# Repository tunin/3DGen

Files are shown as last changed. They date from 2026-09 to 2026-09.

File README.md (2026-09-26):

# Robôzinho — projeto para impressão 3D

Robô paramétrico em [OpenSCAD](https://openscad.org) com ~17 cm de altura:

- **Base** com 4 rodas (2 eixos + travas) e baia para **4 pilhas AA**
- **Torso** com bolso para placa **micro:bit** (a placa desliza por trilhos
  internos a partir de uma fenda no topo) e **2 furos para botões** de 12 mm
- **Cabeça** com janela 34×34 para **matriz de LED 8×8** (~32 mm) ou display
  OLED pequeno — o módulo desliza por trilhos a partir de uma fenda no topo;
  antena e "orelhas" decorativas
- **2 braços articulados** (ombro + cotovelo) com garra de 2 dedos

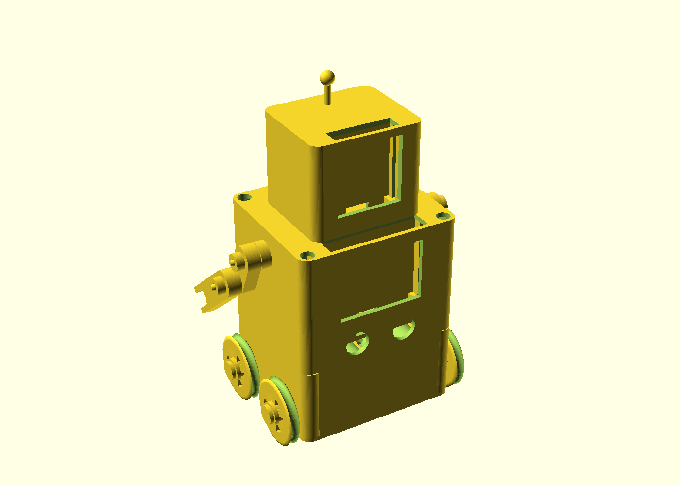
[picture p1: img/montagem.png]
Montagem


**[Manual ilustrado de montagem (PDF)](manual/manual_montagem.pdf)** —
8 etapas em português, com vistas de encaixe e observações essenciais.

Para regenerar o PDF com as peças atuais, instale as dependências de
`manual/requirements.txt` e execute `python manual/gerar_manual.py`.
Requer OpenSCAD; `OPENSCAD` permite indicar o executável. O gerador reutiliza
as imagens intermediárias em `manual/.cache/`; use `--force` para refazê-las.

## Peças para imprimir

| Arquivo STL | Qtd | Observações |
|---|---|---|
| `stl/base.stl` | 1 | Chassi — abertura para cima |
| `stl/corpo.stl` | 1 | Torso — abertura para baixo |
| `stl/cabeca.stl` | 1 | Cabeça — de pé |
| `stl/roda.stl` | 4 | Sulco no aro para elástico como "pneu" |
| `stl/eixo.stl` | 2 | Eixo em pé e trava separados; usar brim (ou eixo metálico M4 de comprimento adequado) |
| `stl/suporte_pilhas.stl` | 1 | Berço 4×AA (ou use suporte comercial) |
| `stl/braco.stl` | 2 | Cada arquivo traz os 2 segmentos do braço |
| `stl/pino.stl` | 4 | Pino + trava das articulações (ou M4×20 + porca) |

## Fatiamento sugerido

- Material: PLA (ou PETG)
- Altura de camada: 0,2 mm — perímetros: 3 — preenchimento: 15–20%
- Torso e cabeça: confira suportes para prateleiras, ressaltos e teto; os painéis internos agora começam na base, mas isso não elimina pontes e balanços. Verifique no fatiador o acesso para remover os suportes antes de imprimir.
- Eixo: imprimir em pé, apoiado na cabeça, com brim. A haste é longa e fina; para maior resistência, prefira eixo metálico. A trava deve aparecer como outra peça, não fundida à haste.
- Rodas: assente o cubo na mesa e confira o suporte sob aro e raios no fatiador.
- Tolerâncias: `folga = 0.3`, `folga_berco = 0.6` e `aperto_trava = 0.1` em `parametros.scad`. O último valor é interferência diametral, não folga radial. Faça um teste de pino/trava antes do lote.
- Imprima os arquivos de peças separadamente. `stl/montagem.stl` é referência visual, não um kit pronto para imprimir: contém contatos e encaixes por pressão intencionais.

## Hardware necessário

- 1 placa **micro:bit** (51,6 × 42 mm)
- 1 **matriz de LED 8×8** MAX7219 (~32 × 32 mm) ou OLED similar — para o rosto
- 2 **botões de painel** de 12 mm
- 1 **suporte de pilhas 4×AA** com interruptor (~62 × 58 × 17 mm)
  — ou use o berço impresso (requer contatos/molas próprios)
- 4 parafusos **M3 × 20** autoroscantes (torso ↔ chassi)
- Articulações dos braços: 4 pinos impressos **ou** parafusos **M4 × 20**
  com porcas autotravantes
- Elásticos/aneis de borracha para os "pneus" das rodas (opcional)

## Montagem

Use base, torso e berço desta mesma revisão: os centros das colunas passaram
para X = ±36,5 mm (Y = ±32 mm). Não misture essas peças com as versões antigas.

1. Monte os botões, os pinos dos ombros e a fiação no torso enquanto o fundo
   está acessível. Os botões ficam abaixo do micro:bit; confira as medidas
   do corpo, da porca e dos terminais do seu modelo.
2. Deslize o micro:bit pela fenda superior até as prateleiras. Passe os fios
   pela abertura do painel interno antes de fechar o conjunto.
3. Apoie o berço impresso ou suporte comercial nas duas travessas elevadas
   do chassi. O plano de apoio fica a 18,6 mm do fundo; a base tem 40 mm de
   altura. O berço tem 0,6 mm de folga nominal nas colunas. Um envelope
   comercial de 62 × 58 × 17 mm, inclusive com cantos retos, cabe centralizado.
4. Conecte a fiação necessária, assente o torso na base e introduza os quatro
   M3 × 20 pelos acessos de 7 mm no topo. Use cabeça de parafuso de até 6 mm
   e chave com haste de até 6 mm, com alcance útil mínimo de 56 mm. Aperte
   nas colunas sem forçar o plástico; não tente parafusar pelo fundo da base.
5. Instale o display e sua fiação na cabeça. Há uma saída sob o display para
   os fios alcançarem o interior e uma passagem central de 12 × 8 mm,
   alinhada à passagem do torso. Confira os conectores antes de fechar.
6. Monte os antebraços pelo lado externo dos cotovelos, com 0,3 mm entre os
   segmentos. Use os pinos atualizados e suas travas ou parafusos M4.
   A montagem de referência agora mostra também os pinos e travas.
7. Encaixe a cabeça nos quatro pinos. Eles têm 4,4 mm de altura e folga axial;
   o encaixe é removível, sem trava de retenção. Não use os fios para segurá-la.
8. Encaixe a primeira roda no eixo antes de atravessar o chassi, depois
   coloque a segunda roda e a trava externa. Repita no outro eixo e confira
   se as rodas giram sem raspar.

### Dimensões da eletrônica

Os testes usam envelopes conservadores, não modelos de componentes específicos:

| Componente | Envelope configurado | Entrada / acomodação |
|---|---|---|
| micro:bit | 51,6 × 42 × 11 mm | Fenda de 52,2 × 11,6 mm; apoio a 18 mm do fundo do torso |
| Display | Até 33 × 33 × 8 mm | Fenda de 33,6 × 8,6 mm; apoio a 8 mm do fundo da cabeça |
| Suporte comercial | 62 × 58 × 17 mm | Centralizado, com cantos retos e sem acessórios fora desse envelope |
| Botões | Corpo de 12 mm, profundidade interna até 10 mm | Porca com envelope de até 16 mm de diâmetro e 3 mm de espessura |

Meça a placa completa, USB/JST, soldas, cabos, interruptor e terminais. Ajuste
`mb_prof`, `led_prof`, `botao_prof` e os demais parâmetros se necessário e
rode os testes novamente. A passagem central não garante a passagem de
qualquer conector: o túnel sob o display tem 12 × 5 mm; um caminho de 3 × 3 mm
para fios foi verificado. O berço impresso continua exigindo contatos elétricos
próprios. A validação mecânica não valida o circuito de alimentação.

## Regenerar os STLs

Requer `openscad` (e `xvfb` para as imagens no Linux). Linux:

```bash
make            # gera stl/*.stl
make img        # gera img/*.png (xvfb-run)
```

Windows (Git Bash, sem `make`/`xvfb`):

```bash
./render_stl.sh   # gera stl/*.stl
./render_img.sh   # gera img/*.png
```

Se `openscad` não estiver no `PATH`, os scripts usam
`C:\Program Files\OpenSCAD\openscad.com` ou a variável `OPENSCAD`.
Os PNGs usam renderização completa (`--render`), evitando artefatos do
preview rápido. Na interface do OpenSCAD, use F6 para conferir a geometria
final; F5 é apenas uma prévia.

Ou diretamente:

```bash
openscad -o stl/roda.stl -D 'part="roda"' robo.scad
```

Peças disponíveis em `part`: `montagem`, `base`, `suporte_pilhas`, `roda`,
`eixo`, `corpo`, `cabeca`, `braco`, `pino`.

## Validação geométrica

Requer Python 3 e OpenSCAD; não usa pacotes Python adicionais:

```bash
python -B -m unittest -v test_geometry
```

Os testes renderizam malhas temporárias e verificam rodas, eixos, pilhas,
berço, articulações e fixadores. Também verificam o layout de impressão do
eixo, acesso dos parafusos e da ferramenta, inserção da eletrônica e do
suporte comercial, espaço dos botões, passagem dos fios e assentamento da
cabeça e do torso. As seções dos painéis internos são verificadas contra o
início de impressão no ar encontrado na auditoria; isso não substitui a
inspeção de todas as camadas no fatiador. Os layouts do braço e do eixo devem
conter exatamente dois sólidos fechados. `OPENSCAD` pode indicar o executável.

As rodas de 36 mm têm 42 mm entre centros (6 mm livres entre elas).
A validação digital não garante as tolerâncias reais da impressora nem o
encaixe de contatos elétricos, molas e suportes comerciais: teste os
encaixes antes de imprimir o conjunto completo.

## Personalizar

Todas as cotas estão em [`parametros.scad`](parametros.scad) — diâmetro das
rodas, dimensões do chassi/torso/cabeça, posição dos botões, tamanho da
janela do display etc. Edite e regenere os STLs.

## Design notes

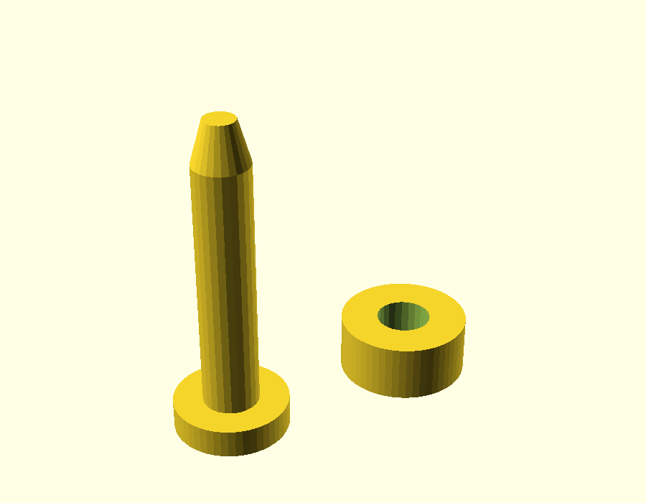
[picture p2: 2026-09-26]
img/pino.png

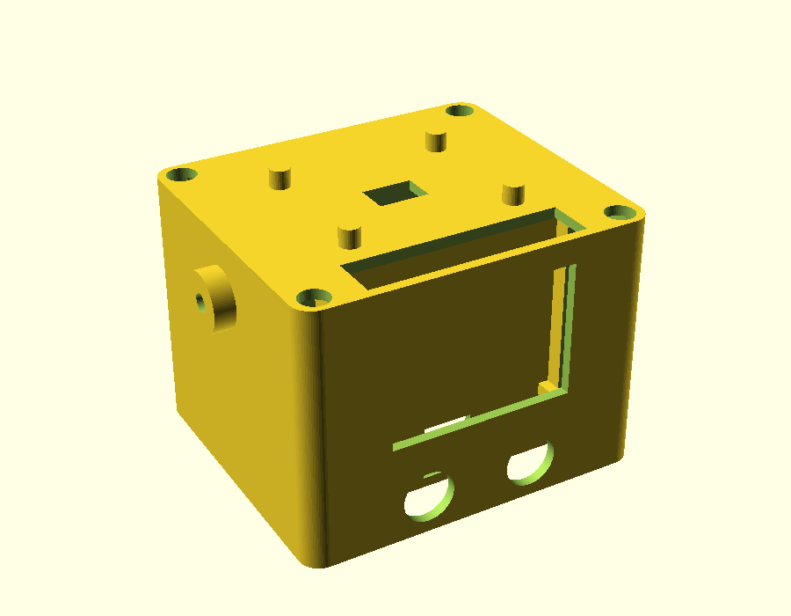
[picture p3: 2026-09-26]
img/corpo.png

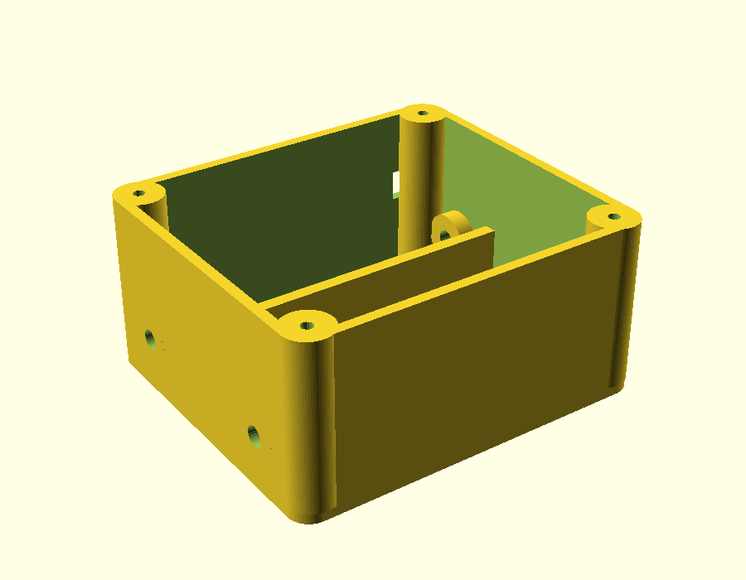
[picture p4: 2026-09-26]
img/base.png

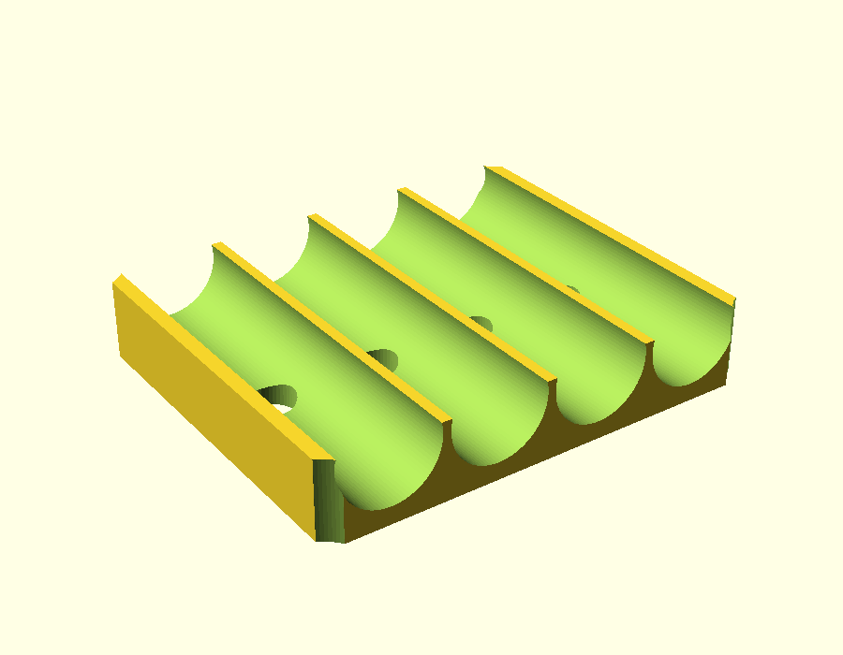
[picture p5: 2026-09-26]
img/suporte_pilhas.png

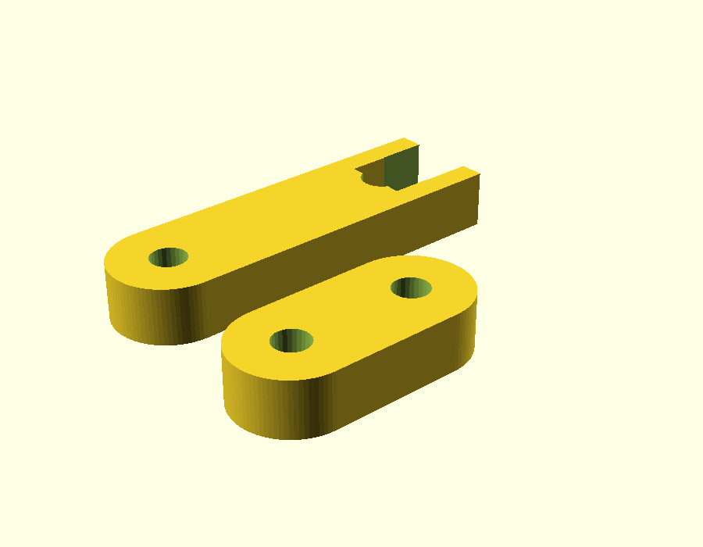
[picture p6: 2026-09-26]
img/braco.png

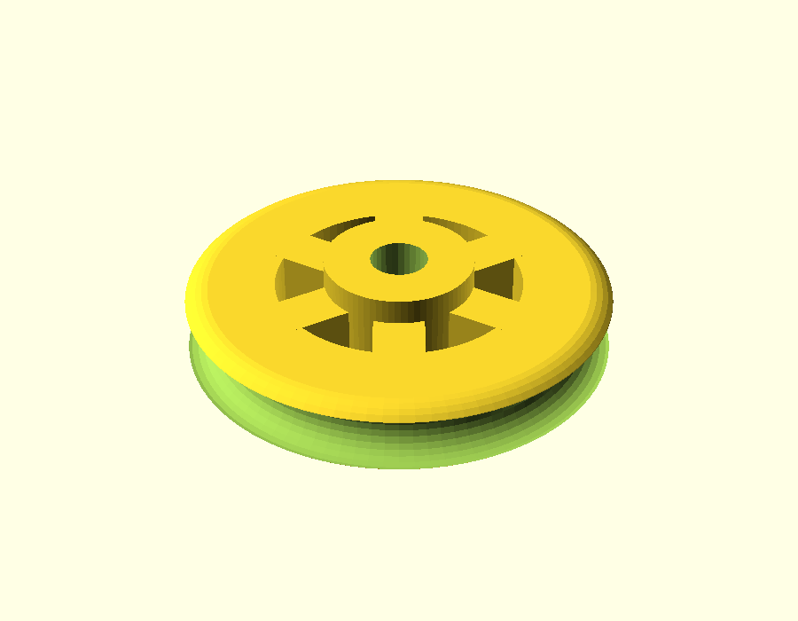
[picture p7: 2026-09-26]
img/roda.png

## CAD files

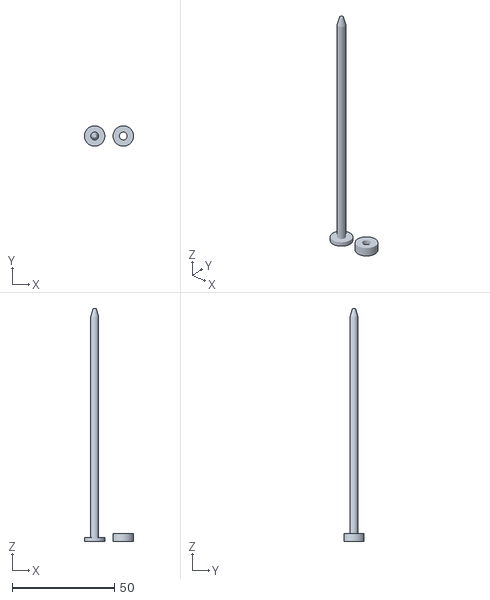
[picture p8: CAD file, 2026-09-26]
stl/eixo.stl
24.0 x 10.00 x 114.0

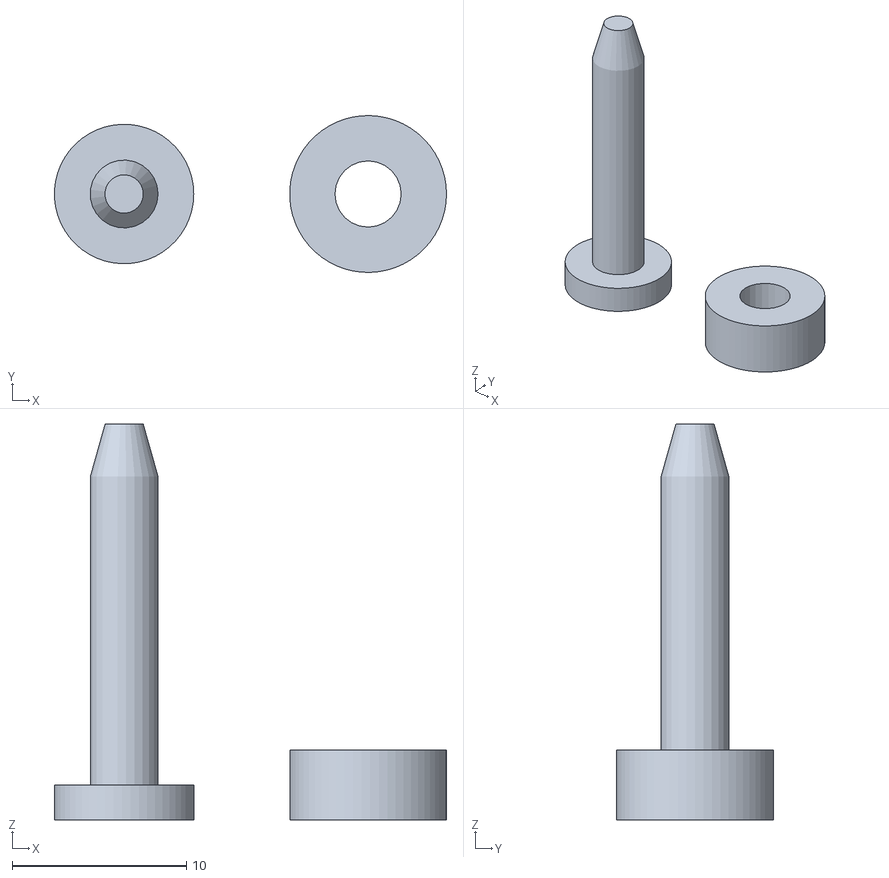
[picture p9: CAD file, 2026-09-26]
stl/pino.stl
22.5 x 9.00 x 22.7

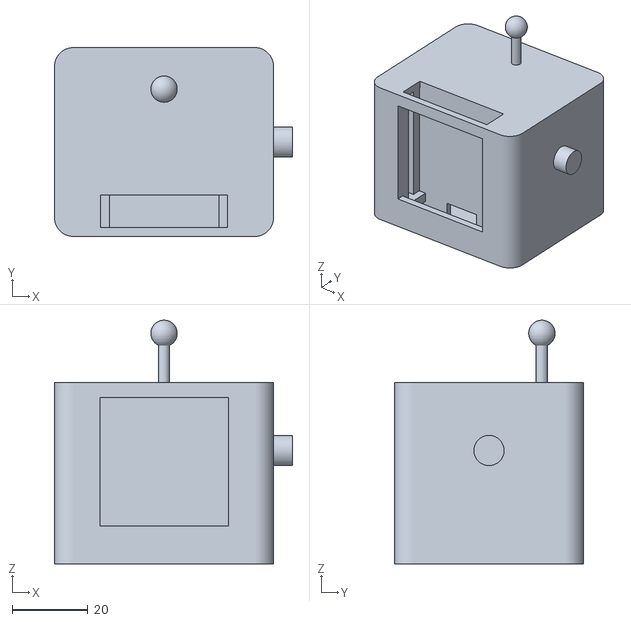
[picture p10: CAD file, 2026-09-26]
stl/cabeca.stl
63.0 x 50.0 x 64.5

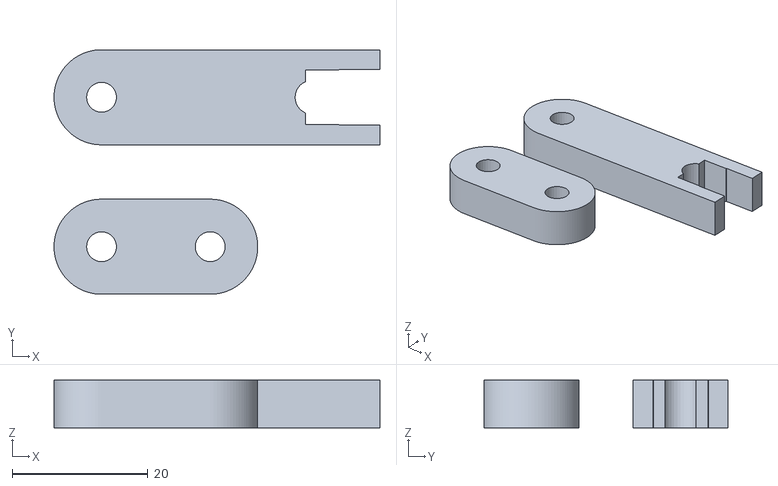
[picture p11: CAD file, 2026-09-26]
stl/braco.stl
48.0 x 36.0 x 7.00

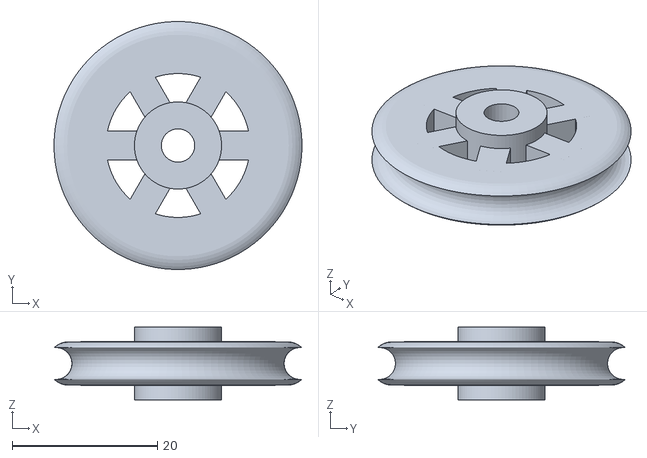
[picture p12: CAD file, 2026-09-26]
stl/roda.stl
34.1 x 34.1 x 10.0

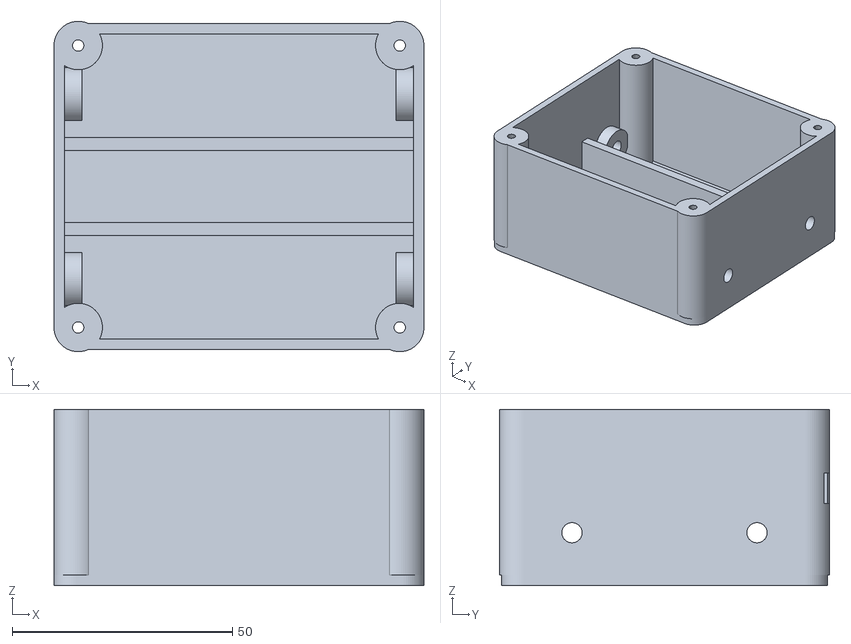
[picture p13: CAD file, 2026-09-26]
stl/base.stl
84.0 x 75.0 x 40.0

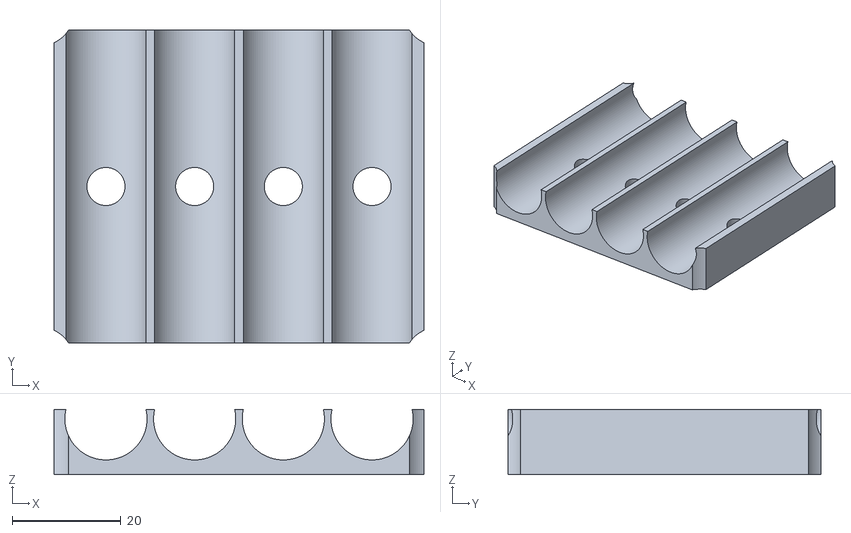
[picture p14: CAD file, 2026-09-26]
stl/suporte_pilhas.stl
68.0 x 57.5 x 12.0

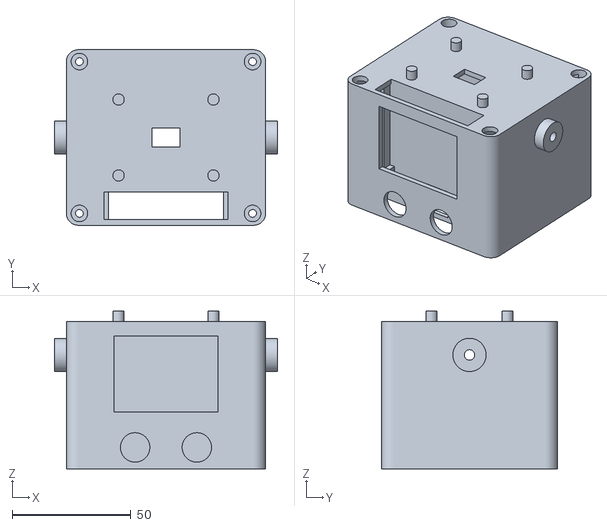
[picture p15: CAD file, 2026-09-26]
stl/corpo.stl
94.0 x 74.0 x 66.4

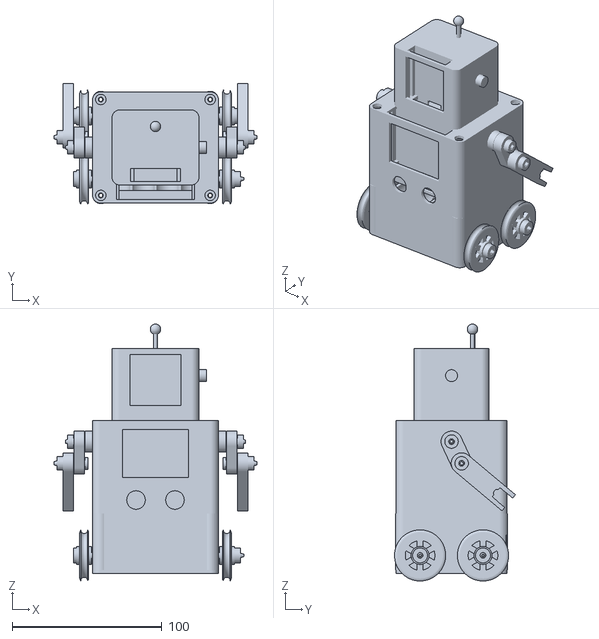
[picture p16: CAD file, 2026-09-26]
stl/montagem.stl
135.4 x 80.7 x 171.6

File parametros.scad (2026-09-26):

// ============================================================
// parametros.scad — dimensões compartilhadas do robô
// Todas as medidas em milímetros.
// ============================================================

$fa = 4;
$fs = 0.5;

// ---------- tolerância de impressão ----------
folga = 0.3;        // folga padrão em furos/encaixes
folga_berco = 0.6;
aperto_trava = 0.1;
passagem_w = 12;
passagem_d = 8;

// ---------- roda ----------
roda_d   = 36;      // diâmetro da roda
roda_w   = 10;      // largura da roda
eixo_d   = 4;       // diâmetro do eixo (haste impressa ou M4)
eixo_l   = 112;     // comprimento do eixo (haste + chanfro)

// ---------- base (chassi) ----------
base_w  = 84;       // largura (X)
base_d  = 74;       // profundidade (Y)
base_h  = 40;       // altura
parede  = 2.4;      // espessura das paredes (todas as peças)
eixo_z  = 12;       // altura do centro do eixo medida do fundo do chassi
roda_y  = roda_d/2 + 3;       // distância do centro do chassi ao centro de cada roda (Y)

// ---------- compartimento das pilhas ----------
// baia dimensionada para suporte comercial 4xAA (~62 x 58 x 17)
// ou para o suporte impresso em suporte_pilhas.scad
aa_bay_w = 72;
aa_bay_d = 58;
aa_dia   = 14.5;    // diâmetro da pilha AA
aa_comp  = 50.5;    // comprimento da pilha AA
suporte_z = eixo_z + 6 + 2*folga;
roda_x = base_w/2 + 2*folga + roda_w/2;
eixo_x = -roda_x - roda_w/2 - folga;

assert(2*roda_y >= roda_d + 2, "Rodas sem folga longitudinal");
assert(roda_y + 6 <= base_d/2, "Buchas fora do chassi");
assert(suporte_z + max(3 + aa_dia, 17) + folga <= base_h,
       "Pilhas acima do topo do chassi");
assert(eixo_z - eixo_d/2 - folga >= parede, "Eixo invade o fundo do chassi");
assert(eixo_x + eixo_l - 4 >= roda_x + roda_w/2 + folga + 2,
       "Eixo curto para as rodas e a trava");

// ---------- corpo (torso) ----------
// mesma pegada do chassi: as paredes alinham e as colunas de
// fixação ficam uma sobre a outra
corpo_w = 84;
corpo_d = 74;
corpo_h = 62;

// posição das colunas de fixação torso↔base (parafuso M3)
mont_x = 36.5;
mont_y = 32;
acesso_m3_d = 7;

// ---------- micro:bit ----------
mb_w    = 51.6;     // largura da placa
mb_h    = 42;       // altura da placa
mb_prof = 11;       // profundidade do bolso (placa + componentes + fios)
mb_base_z = 18;

// ---------- botões ----------
botao_d   = 12.4;   // botão de painel de 12 mm
botao_sep = 26;     // distância entre centros dos botões
botao_z = 9;
botao_prof = 10;
botao_porca_d = 16;

// ---------- cabeça ----------
cab_w   = 58;
cab_d   = 50;
cab_h   = 48;
led_tam = 33;       // janela p/ matriz LED 8x8 (~32 mm) ou OLED pequeno
led_prof = 8;       // profundidade do alojamento do display
led_base_z = 8;
cab_pino_h = led_base_z - 3 - 2*folga;

assert(mb_base_z + mb_h + folga <= corpo_h, "Microbit acima do torso");
assert(led_base_z + led_tam + folga <= cab_h - parede, "Display acima da cabeca");
assert(cab_pino_h > parede, "Pino da cabeca sem engate");
assert(botao_z + botao_porca_d/2 + folga <= mb_base_z, "Botoes invadem a placa");
assert(botao_prof + folga < mb_prof + 2*folga, "Botoes invadem o painel interno");
assert(acesso_m3_d >= 6 + 2*folga, "Acesso insuficiente para cabeca do parafuso");
assert(aperto_trava > 0 && aperto_trava <= 0.2, "Calibre a interferencia das travas");

// ---------- braço ----------
braco_furo = 4.4;   // furo da articulação (parafuso M4 ou pino impresso)
braco_e    = 7;     // espessura dos segmentos do braço
brac_a     = 16;    // distância entre furos do segmento superior
brac_b     = 16;    // comprimento do antebraço até a palma
brac_r     = 7;     // raio das extremidades arredondadas

// ---------- auxiliar: caixa com cantos arredondados ----------
// caixa de w x d x h, centrada em X/Y, base em z = 0
module rbox(w, d, h, r = 3) {
    hull()
        for (x = [-1, 1], y = [-1, 1])
            translate([x * (w/2 - r), y * (d/2 - r), 0])
                cylinder(r = r, h = h);
}

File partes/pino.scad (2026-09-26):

// ============================================================
// pino.scad — pino articulado para os ombros e cotovelos
// Imprimir 4x o pino e 4x a trava (ombro e cotovelo de 2 braços).
// Alternativa mais robusta: parafuso M4x20 + porca autotravante.
// ============================================================

include <../parametros.scad>

pino_l = max(2*braco_e, parede + 5 + braco_e) + folga + 3;   // comprimento útil (parede + ressalto + braço)

module pino() {
    union() {
        cylinder(d = 8, h = 2);                    // cabeça
        translate([0, 0, 2])
            cylinder(d = braco_furo - 0.5, h = pino_l);  // haste
        translate([0, 0, 2 + pino_l])
            cylinder(d1 = braco_furo - 0.5, d2 = braco_furo - 2.2,
                     h = 3);                        // ponta cônica
    }
}

module trava_pino() {
    // capa de pressão para a ponta do pino
    difference() {
        cylinder(d = 9, h = 4);
        translate([0, 0, -0.1])
            cylinder(d = braco_furo - 0.5 - aperto_trava, h = 4.2);
    }
}

// layout para impressão
pino();
translate([14, 0, 0]) trava_pino();

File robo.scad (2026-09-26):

// ============================================================
// robo.scad — arquivo principal do projeto
// Use a variável "part" (linha de comando ou customizador) para
// escolher o que renderizar:
//   montagem       — robô completo montado (visualização)
//   base           — chassi
//   suporte_pilhas — berço para 4 pilhas AA
//   roda           — roda (imprimir 4x)
//   eixo           — eixo + trava (imprimir 2x)
//   corpo          — torso
//   cabeca         — cabeça
//   braco          — braço, 2 peças (imprimir 2x)
//   pino           — pino + trava de articulação (imprimir 4x)
//
// Ex.: openscad -o stl/roda.stl -D 'part="roda"' robo.scad
// ============================================================

part = "montagem";

include <parametros.scad>
use <partes/base.scad>
use <partes/suporte_pilhas.scad>
use <partes/roda.scad>
use <partes/eixo.scad>
use <partes/corpo.scad>
use <partes/cabeca.scad>
use <partes/braco.scad>
use <partes/pino.scad>

// altura do fundo do chassi acima do solo (vão livre)
z_base = roda_d/2 - eixo_z;   // = 6 mm
z_corpo = z_base + base_h;    // torso sobre o chassi
z_cabeca = z_corpo + corpo_h; // cabeça sobre o torso

// ---------- braço montado (ombro + cotovelo articulados) ----------
module braco_montado() {
    rotate([90, 0, 90]) {
        // segmento superior inclinado para fora e para baixo
        rotate([0, 0, -65])
            braco_sup();
        // antebraço a partir do cotovelo
        translate([brac_a * cos(65), -brac_a * sin(65), braco_e + folga])
            rotate([0, 0, -40])
                braco_inf();
    }
}

module fixadores_braco() {
    translate([-(parede + 5 + 2*folga + 2), 0, 0])
        rotate([0, 90, 0]) pino();
    translate([braco_e + folga, 0, 0])
        rotate([0, 90, 0]) trava_pino();
    translate([-2 - folga, brac_a*cos(65), -brac_a*sin(65)])
        rotate([0, 90, 0]) pino();
    translate([2*braco_e + 2*folga, brac_a*cos(65), -brac_a*sin(65)])
        rotate([0, 90, 0]) trava_pino();
}

module montagem() {
    // chassi
    color("#3f7fbf") translate([0, 0, z_base]) base();
    // berço das pilhas
    color("#e0a030") translate([0, 0, z_base + suporte_z])
        suporte_pilhas();
    // eixos + rodas
    for (y = [-1, 1]) {
        color("#c04040")
            translate([eixo_x, y * roda_y, z_base + eixo_z])
                eixo();
        color("#c04040")
            translate([roda_x + roda_w/2 + folga, y * roda_y, z_base + eixo_z])
                rotate([0, 90, 0]) trava_eixo();
        for (x = [-1, 1])
            color("#404040")
                translate([x * roda_x, y * roda_y, z_base + eixo_z])
                    rotate([0, 90, 0]) roda();
    }
    // torso
    color("#40a060") translate([0, 0, z_corpo]) corpo();
    // cabeça
    color("#e0e0e0") translate([0, 0, z_cabeca]) cabeca();
    // braços nos ombros
    for (x = [-1, 1])
        color("#8060c0")
            translate([x * (corpo_w/2 + 5 + folga), 0,
                       z_corpo + corpo_h - 14])
                scale([x, 1, 1]) {
                    braco_montado();
                    fixadores_braco();
                }
}

if (part == "montagem")       montagem();
else if (part == "base")           base();
else if (part == "suporte_pilhas") suporte_pilhas();
else if (part == "roda")           roda();
else if (part == "eixo")           eixo_impressao();
else if (part == "corpo")          corpo();
else if (part == "cabeca")         cabeca();
else if (part == "braco")          braco();
else if (part == "pino")           { pino(); translate([14,0,0]) trava_pino(); }
else echo("part desconhecida:", part);

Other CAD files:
manual/montagem.scad
partes/base.scad
partes/braco.scad
partes/cabeca.scad
partes/corpo.scad
partes/eixo.scad
partes/roda.scad
partes/suporte_pilhas.scad

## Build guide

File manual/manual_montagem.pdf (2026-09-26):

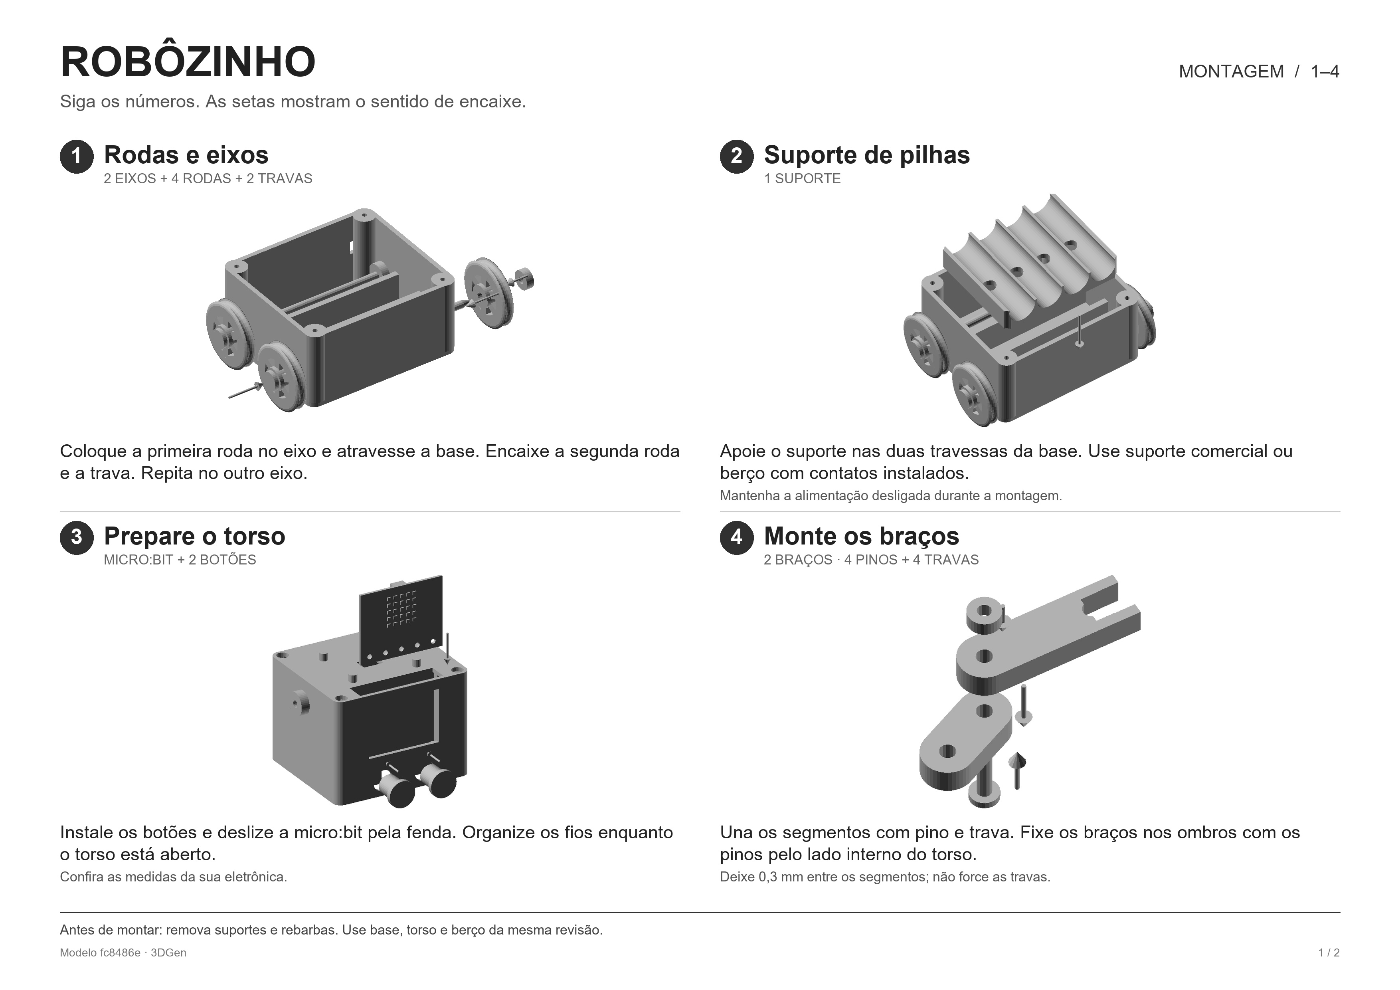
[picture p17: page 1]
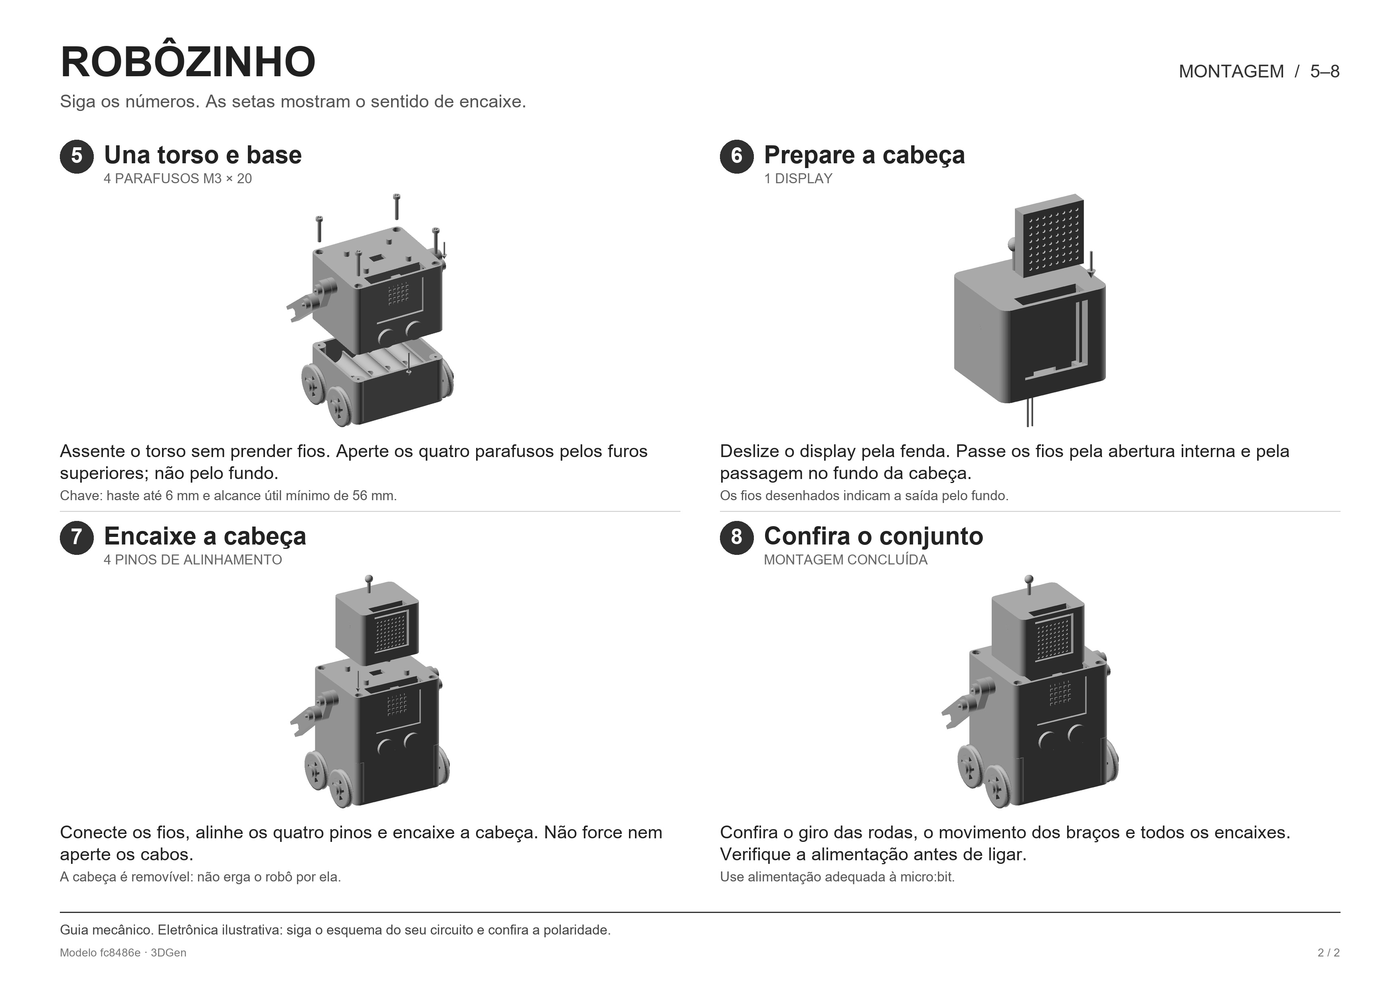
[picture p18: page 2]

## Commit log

2026-09-25 Robôzinho: projeto OpenSCAD paramétrico para impressão 3D
    Robô de ~15 cm: chassi com 4 rodas em 2 eixos, baia para 4 pilhas AA,
    torso com bolso deslizante para micro:bit e 2 furos para botões de 12 mm,
    cabeça com janela para matriz de LED 8x8, e 2 braços articulados com
    ombro + cotovelo (pinos impressos ou parafusos M4).
    - robo.scad: seletor de peça + montagem completa
    - parametros.scad: todas as cotas em um só lugar
    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
    [base.scad, base.stl, braco.scad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]
2026-09-26 Corrige buchas dos eixos assimetricas na base
    [base.scad]
2026-09-26 Regenera STL e previews da base
    [base.stl, montagem.stl]
2026-09-26 Permite regenerar STLs e previews no Windows
    Adiciona render_stl.sh (equivalente ao `make`) e torna render_img.sh
    independente de xvfb, com fallback para o OpenSCAD em Program Files.
    Generated with [Devin](https://devin.ai)
2026-09-26 Evita interferencias nas rodas, pilhas e articulacoes do robo
    Afasta as rodas, apoia o berco acima dos eixos e libera seus cantos
    nas colunas. Une os dedos a palma, alinha os furos do braco e ajusta
    os pinos. Inclui testes geometricos e artefatos regenerados com
    previews renderizados para evitar omissao dos aros no OpenCSG.
    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
    [base.scad, base.stl, braco.scad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]
2026-09-26 Corrige bloqueios de montagem e acesso ao hardware do robo
    Separa eixo e trava, libera parafusos e fios, dimensiona entradas
    para a eletronica e afasta as colunas do suporte comercial.
    Apoia os paineis internos, conecta guias e prateleiras e ajusta
    as folgas dos fixadores. Inclui 24 testes geometricos, STLs,
    previews e instrucoes de montagem e impressao atualizados.
    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
    [base.stl, braco.stl, cabeca.scad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]
2026-09-26 Adiciona manual ilustrado de montagem em portugues
    Manual em PDF com 8 etapas numeradas e vistas de encaixe geradas
    a partir da geometria atual do modelo. Inclui gerador que renderiza
    as ilustracoes no OpenSCAD e monta as paginas com Pillow.
    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
    [montagem.scad]
